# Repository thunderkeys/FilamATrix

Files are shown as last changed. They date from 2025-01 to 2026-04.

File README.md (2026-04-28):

# FilamATrix Mod

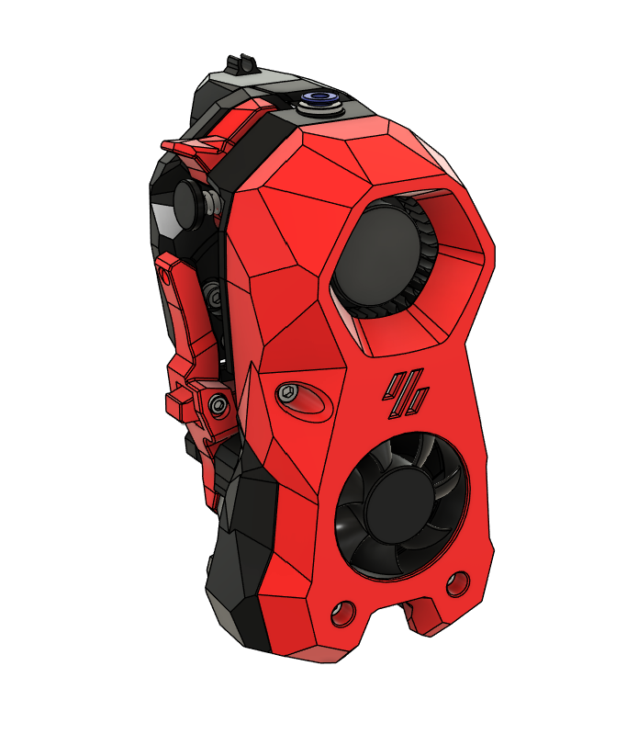
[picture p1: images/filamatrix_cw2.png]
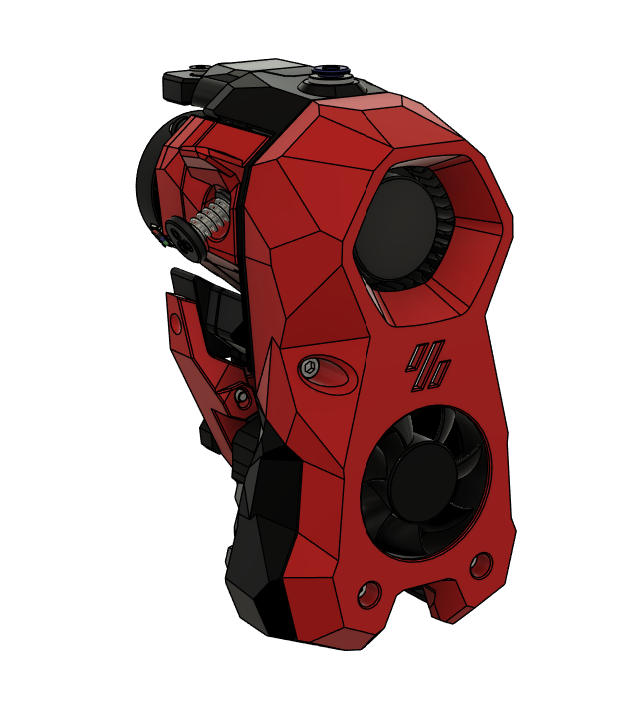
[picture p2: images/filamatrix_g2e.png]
 

FilamATrix is a Stealthburner toolhead filament cutting mod created specifically for the ArmoredTurtle [BoxTurtle](https://github.com/ArmoredTurtle/BoxTurtle) project.  It is an adaptation and cleanup of the [Filametrix](https://github.com/sorted01/Filametrix) and [G2E-Filametrix](https://github.com/IRTrail/G2E-Filametrix) mods. Note the slightly different spelling change - all other documentation within this repository refers to this specific modification.

However, use of BoxTurtle/AFC are not required - this mod can be used anywhere the upstream Filametrix/G2E-Filametrix are.

FilamATrix modifies the [VORON Design](https://www.vorondesign.com) [StealthBurner hotend and Clockwork 2 Extruder](https://github.com/VoronDesign/Voron-Stealthburner/) or [Galileo 2 Extruder](https://github.com/JaredC01/Galileo2/tree/main/galileo2_extruder) to support a kinematic-actuated cutting blade for cleaner, more reliable automated filament changes that also eliminates the need for tip forming.

FilamATrix consolidates the CAD for Filametrix and G2E-Filametrix into a single file and provides a reorganized repository with a clear structure of what files are needed to print.  While both extruders are provided as an option, our recommendation is to use Clockwork 2 - we find users have had the most success with it. The assembly instructions and manual only cover Clockwork 2.

Clockwork 2 supports two toolhead sensors, but some users may only be able to support one due to limited GPIO on the toolhead. With current AFC software, our default recommendation is to not use physical toolhead sensors and instead use the buffer as a [ram sensor](https://www.armoredturtle.xyz/docs/afc-klipper-add-on/installation/buffer-ram-sensor.html).

The print files for FilamATrix have been modified from the original projects with the following changes:

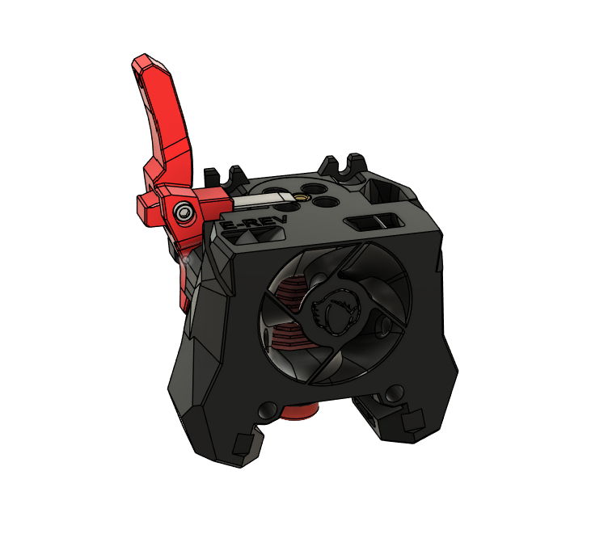
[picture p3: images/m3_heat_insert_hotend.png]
- Hotend mounts/Printheads now use an M3 threaded heat insert (instead of an M3 nut) for simpler installation and maintenance.  Many thanks to [hartk](https://github.com/hartk1213) for this idea!<br>

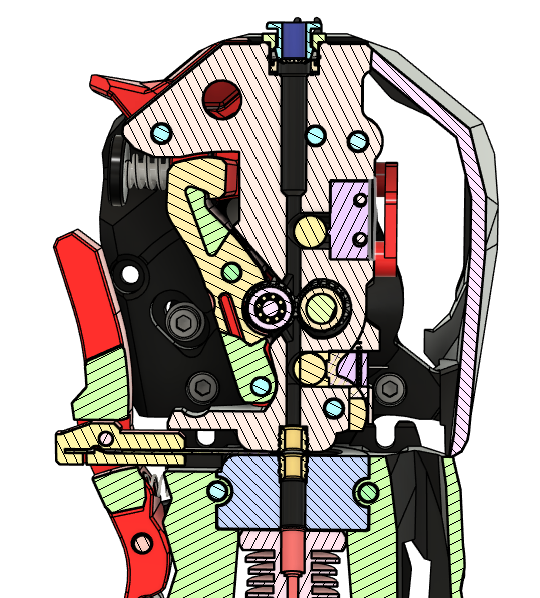
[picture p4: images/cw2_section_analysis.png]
- On Clockwork 2, there is an increased depth for the PTFE tubing to better help guide the filament towards the extruder gears and make insertion less position dependent.<br>

- Cutting arm has been modified to support a full length M2.5x16 FHCS.

- Inclusion of the Beefy Depressor mount as the default.

## Supported hotends
The following hotends are natively supported on this repository:
- Revo Voron
- Dragon HF
- Dragon UHF
- Dragon UHF mini
- Rapido HF v1/v2
- Rapido UHF v1/v2
- Bambulab X1C

The following are user-contributed hotend mounts, please direct any issues with them to their respective creators:
- [TZ V6 2.0 by Adam Storm on Printables](https://www.printables.com/model/1170130-filamatrix-tz-v6-20-hotend-mount)

If you would like to have a hotend mount that you have created added to the above lists, please contact thunderkeys on the [ArmoredTurtle discord](https://discord.gg/armoredturtle) in the toolheads channel.

## Files to print
**LDO Kit users** - If you are running a recent RevD LDO kit with the stock Revo Voron hotend, print [these files](https://github.com/thunderkeys/FilamATrix/blob/main/STLs/LDO/LDO.zip).

**Non-LDO kits/Other users, print these files**
- [beefy_depressor_mount.stl](https://github.com/thunderkeys/FilamATrix/blob/main/STLs/beefy_depressor_mount.stl)
- [beefy_depressor.stl](https://github.com/thunderkeys/FilamATrix/blob/main/STLs/beefy_depressor.stl)
- Respective parts for your extruder - [Clockwork2](https://github.com/thunderkeys/FilamATrix/tree/main/STLs/Clockwork2/README.md) (Recommended) or [Galileo2_Extruder](https://github.com/thunderkeys/FilamATrix/tree/main/STLs/galileo2_extruder/README.md)
- [Stealthburner modified parts](https://github.com/thunderkeys/FilamATrix/tree/main/STLs/Stealthburner/README.md) - pick the set (front+rear) specific to your Printhead/Hotend
- [cutting jig for your hotend](https://github.com/thunderkeys/FilamATrix/blob/main/STLs/README.md) - use a razor blade to cut a section of 2mm ID PTFE to length for your hotend.

**All files**
All files are located on this GitHub in the [STLs folder](https://github.com/thunderkeys/FilamATrix/blob/main/STLs)

## Print settings
All files are to be printed using 'VORON Standard' parts settings/filaments:

| | |
| - | - |
| **3D Printing Process:** Fused Deposition Modeling (FDM) | **Infill Type:** Grid, Gyroid, Honeycomb, Triangle or Cubic |
| **Material:** ABS/ASA | **Infill Percentage:** 40% |
| **Layer Height:** 0.2mm | **Wall Count:** 4 |
| **Extrusion width:** Forced 0.4mm | **Solid Top/Bottom Layers:** 5 |

## Bill of Materials
BoxTurtle kits provided by LDO or Isik's Tech come with all of the physical hardware necessary for FilamATrix, but below is the BOM needed to build it.

 Item    | Quantity | Notes | Source
 ----   | -------- | ------ | -----
ECAS04 Bowden Collet | 1 | | [Amazon](https://www.amazon.com/Pneumatic-Connector-Extruder-Printer-Accessories/dp/B0CFYRGXS3) \| [AliExpress](https://www.aliexpress.us/item/3256805436525602.html)
M3 hex nut | 1 | DIN934 | [McMaster-Carr](https://www.mcmaster.com/90591A250/) \| [AliExpress](https://www.aliexpress.us/item/2255800690659531.html)
M3 washer | 2 | 0.5mm thickness | [KB-3D](https://kb-3d.com/store/inserts-fasteners-adhesives/287-3x6x05mm-shim-ring-washer-pack-of-50-din988-1634423217623.html)
M3x16 BHCS | 1 | | [AliExpress](https://www.aliexpress.us/item/2251832624537980.html)
M3x18 SHCS | 1 | | [AliExpress](https://www.aliexpress.us/item/2251832624557792.html)
M3x20 SHCS | 1 | For Clockwork 2 upper left shroud screw | [AliExpress](https://www.aliexpress.us/item/2251832624557792.html)
M3xD5xL4 Threaded Heatset insert | 5 | | [AliExpress](https://www.aliexpress.us/item/2255800046543591.html)
M3x16 FHCS | 1 | | [AliExpress](https://www.aliexpress.us/item/3256804926092900.html)
M3x18 FHCS | 1 | | [AliExpress](https://www.aliexpress.us/item/3256804926092900.html)
M3x8 SHCS | 1 | | [AliExpress](https://www.aliexpress.us/item/2251832624557792.html)
M3x10, M3x12 or M3x16 SHCS | 2 | 10mm - no backers, 12mm - titanium backers, 16mm - MGN9 rails | [AliExpress](https://www.aliexpress.us/item/3256804926092900.html)
M3 roll-in T-Nut | 2 | | [AliExpress](https://www.aliexpress.us/item/2251832618848960.html)
M2.5x16 SHCS | 1 |  | [AliExpress](https://www.aliexpress.us/item/2251832747871730.html)
0.5mm x 4mm x 25mm coil spring | 1 | A spring from a [common ballpoint pen](https://www.amazon.com/U-S-Government-Pen-Medium-Point/dp/B0055KSO3A) can also work | [Amazon](https://www.amazon.com/uxcell-Compression-Spring-Stainless-Length/dp/B0CGZRR4JT) \| [AliExpress](https://www.aliexpress.us/item/3256803316195677.html)
Type 4 metal hobby blade or OLFA KB4-F/5 8mm chisel blade | 1 | If using the legacy blade holder or G2E), this *may* need to be trimmed to length (approximately 26mm) after purchase. Some suppliers pre-trim the blade (Formbot, West3D Berserker Knifr) | [Amazon Hobby 4](https://www.amazon.com/HARFINGTON-Replacement-Precision-Refills-Scrapbooking/dp/B0CBLRNXSV) \| [OLFA Website](https://olfa.com/products/olfa-kb4-f-5-chisel-art-blades-5pk#shop) \| [Amazon OLFA](https://www.amazon.com/OLFA-9166-KB4-F-Chisel-5-Pack/dp/B000BNXOOU) \| [AliExpress OLFA](https://www.aliexpress.us/item/3256805333623451.html)
D2F limit switch | 1-2 | One per extruder sensor (default with AFC is no physical sensor) | [DigiKey](https://www.digikey.com/en/products/detail/omron-electronics-inc-emc-div/D2F/83270)
5.5mm steel ball-bearing | 1-2 | One per extruder sensor (default with AFC is no physical sensor) | [Amazon](https://www.amazon.com/uxcell-50pcs-Stainless-Bearing-Precision/dp/B09DSH1GL6)
M2x10 Self-tapping screw | 2-4 | Two per extruder sensor | [Amazon](https://www.amazon.com/Hexagon-Socket-Tapping-Screws-M2x10mm/dp/B00YBMROKC)
PTFE Wire | 24-26 gauge | Wire is required to connect the toolhead sensors to your printer. This is extremely build dependent and specifics are not covered here. |
Skittles | User-dependent | Optional, but in case you feel like being a completionist while progressing through the manual. | [Amazon](https://www.amazon.com/Skittles-Original-Candy-Ounce-Jar/dp/B08CS147FX)

## Assembly and Installation
Please review this [interactive manual](https://armoredturtle.xyz/manual.html?manual=filamatrix) for assembly and installation instructions of FilamATrix.

One thing to note is that the stock Stealthburner uses M3x25 SHCS for the upper screws securing the shroud to the extruder. The left screw needs to be an **M3x20** SHCS on FilamATrix to allow the cutting arm to fully depress.

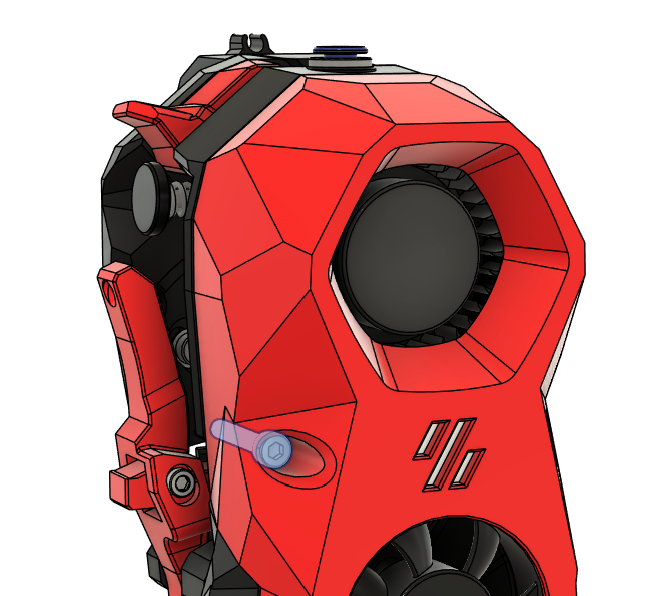
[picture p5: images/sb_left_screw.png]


## Preparing and mounting of the Beefy Depressor

Install M3 heatsets on both sides of the beefy depressor pin. Attach the pin to the mount using the M3x16 FHCS. Thread the M3 hexnut onto the M3x16 BHCS and install that on the end facing into the printer.  Use the hexnut to 'lock' the screw into position, you may wish to use Loctite or VC-3 here on this screw. Careful not to get Loctite on any ABS/ASA printed parts!

Attach the assembled mount to the gantry using M3 screws (place M3 washers between the screws and the printed part).  The length of the screw will likely be printer-dependent, see above BOM for suggested sizes.

Once installed, adjust the height of the pin on the mount and the depth of the screw so it will depress the cutting arm when the toolhead hits against it (going from right to left).

Depending on your printer you may find it more advantageous to mount the beefy depressor at the rear, or at the front.  See below for example mounting locations on an example Voron 2.4 printer gantry.

### Rear
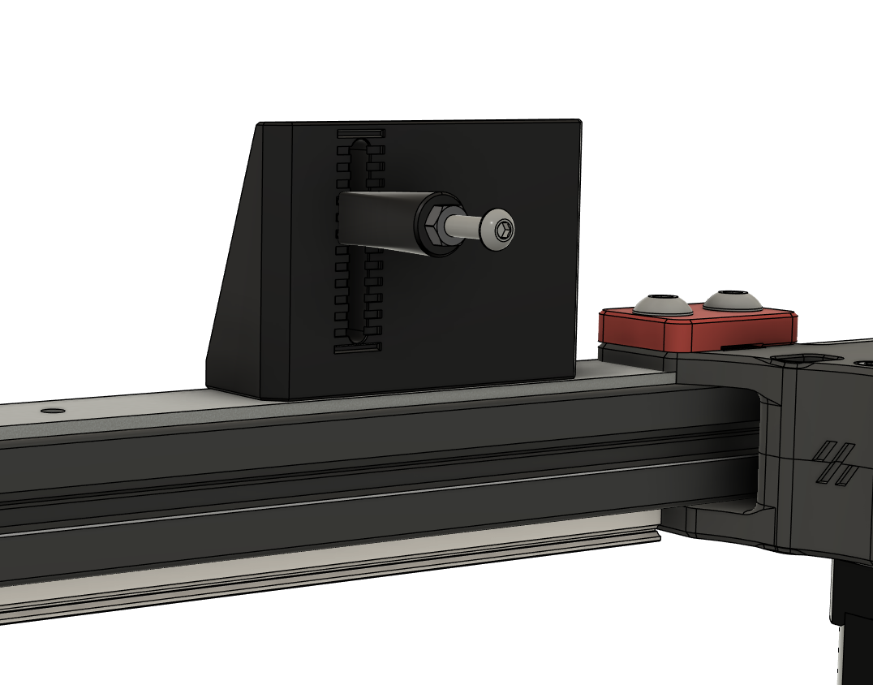
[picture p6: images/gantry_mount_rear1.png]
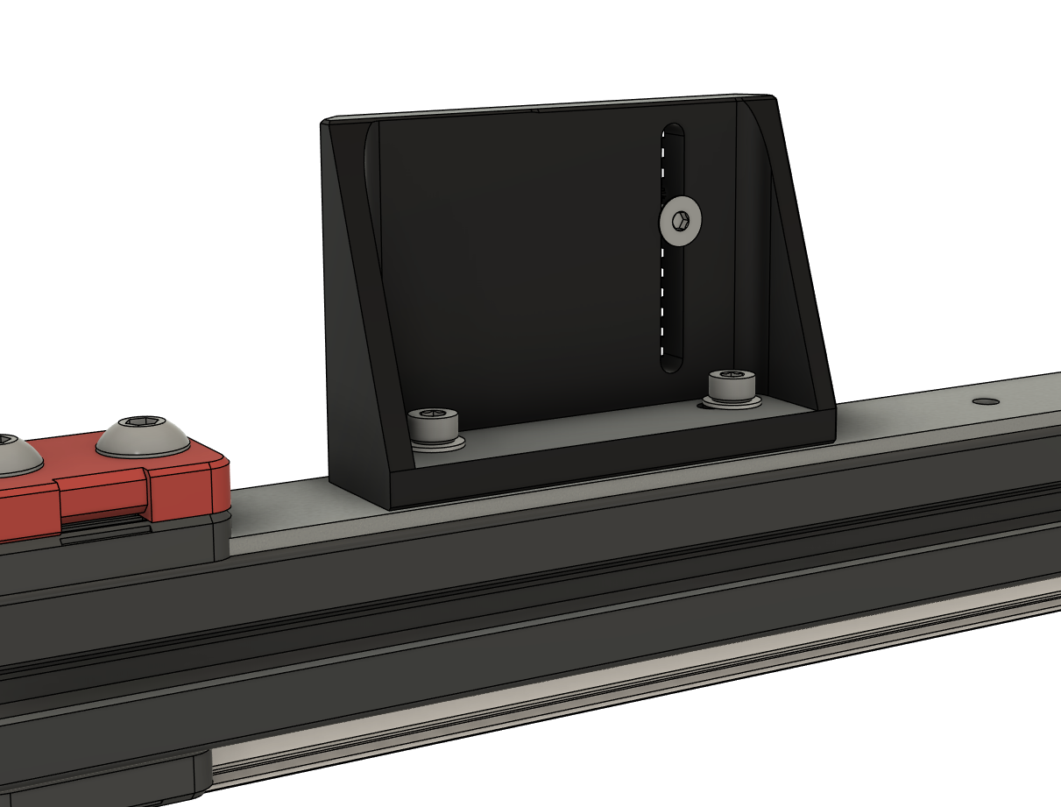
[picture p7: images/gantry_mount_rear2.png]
 

### Front
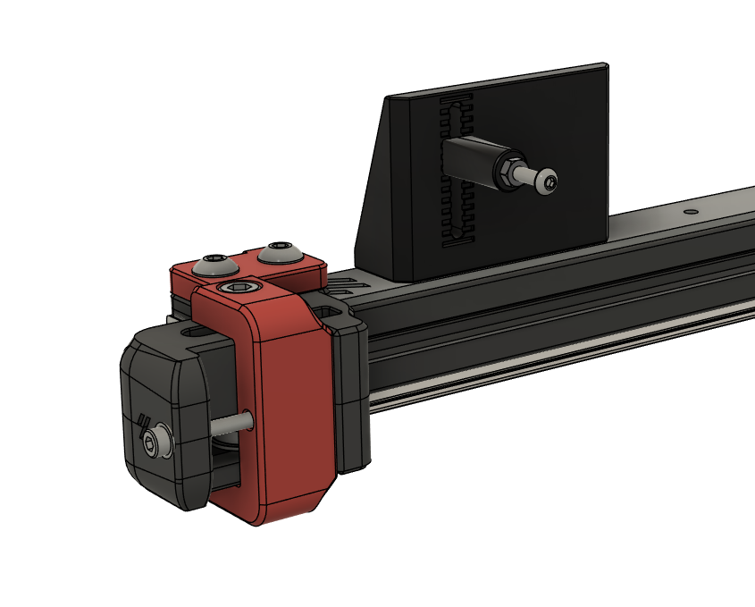
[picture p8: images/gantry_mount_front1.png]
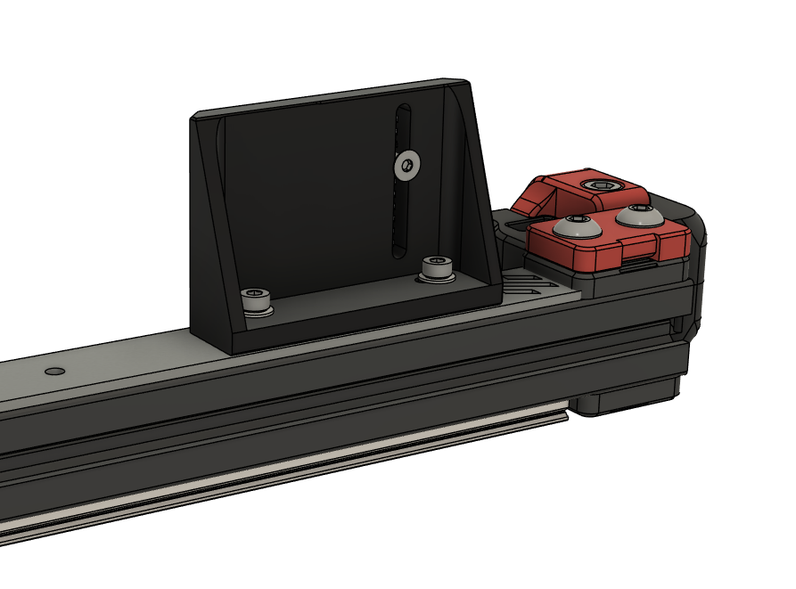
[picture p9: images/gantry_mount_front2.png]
 

## AFC Configuration

Now that FilamATrix is installed, configure your software to leverage it.  If you are using the [AFC Klipper Add-On](https://github.com/ArmoredTurtle/AFC-Klipper-Add-On), you'll need to configure the locations to actuate the cutter arm.
For further guidance you can also see the BoxTurtle [Initial Startup](https://github.com/ArmoredTurtle/BoxTurtle/blob/main/Initial_Startup.md) guide.

If you are using other software, please refer to that project for the correct configuration.

- Home all printer axes (e.g., using G28)
- Use mainsail/fluidd/klipperscreen/etc controls to jog the toolhead near the cutting pin.  This will likely be near X minimum (e.g. X=15-20) and Y maximum if installed in the default location.
- Move the toolhead in 1mm increments until you are just about to depress the pin.  Make note of these coordinates.
- Continue to move the toolhead in 1mm increments until the cutting arm is fully depressed. Make a note of the fully depressed coordinates.
- Ensure ``tool_cut: true`` is set in ``AFC/AFC.cfg`` (it is also recommended to enable the park, kick, poop and wipe macros)
- Update ``AFC/AFC_Macro_Vars.cfg`` with these values as per the comments in the ``_AFC_CUT_TIP_VARS`` section.  

## Acknowledgements
- [Wondro](https://github.com/Wondro) and [ArmoredTurtle](https://github.com/ArmoredTurtle/) for the modified CAD for FilamATrix
- [hartk](https://github.com/hartk1213) for the idea to use an M3 threaded heat insert for the hotend mount
- [sorted01](https://github.com/sorted01) for the original [Filametrix](https://github.com/sorted01/Filametrix) project - you can [donate here](https://www.paypal.com/paypalme/sorted01) if interested
- [IRTrail](https://github.com/IRTrail) for the [G2E-Filametrix](https://github.com/IRTrail/G2E-Filametrix) project (now archived as read-only, as of 2024-12-12).
- [VORON Design](https://www.vorondesign.com) for Stealthburner and Clockwork2
- [JaredC01](https://github.com/JaredC01) for Galileo2
- ChainsDD for the G2E-FilamATrix files to support EBB USB toolhead boards
- [KinematicDigit](https://github.com/kinematicdigit) for the idea on housing full length blades in the knife holder (originally seen with [JabberWocky](https://github.com/kinematicdigit/Jabberwocky)).

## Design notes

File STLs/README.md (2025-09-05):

## Files to print

- [beefy_depressor_mount.stl](https://github.com/thunderkeys/FilamATrix/blob/main/STLs/beefy_depressor_mount.stl) OR [beefy_depressor_mount_cable_chain.stl](https://github.com/thunderkeys/FilamATrix/blob/main/STLs/beefy_depressor_mount_cable_chain.stl) (may be needed if using cable chains on X)
- [beefy_depressor.stl](https://github.com/thunderkeys/FilamATrix/blob/main/STLs/beefy_depressor.stl)
- [razor_safety_cap.stl](https://github.com/thunderkeys/FilamATrix/blob/main/STLs/razor_safety_cap.stl) OR [razor_safety_cap_olfa.stl](https://github.com/thunderkeys/FilamATrix/blob/main/STLs/razor_safety_cap_olfa.stl) - don't cut the bleedy bits of your fingers on the #4 hobby blade
- Respective parts for your extruder - [Clockwork2](https://github.com/thunderkeys/FilamATrix/tree/main/STLs/Clockwork2) or [Galileo2_Extruder](https://github.com/thunderkeys/FilamATrix/tree/main/STLs/galileo2_extruder)
- [Stealthburner modified parts](https://github.com/thunderkeys/FilamATrix/tree/main/STLs/Stealthburner) - pick the set (front+rear) specific to your Printhead/Hotend

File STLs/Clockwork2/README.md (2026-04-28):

# Clockwork2 files

Print one each of:

- [\[a\]\_cutting_arm_clockwork2.stl](https://github.com/thunderkeys/FilamATrix/blob/main/STLs/Clockwork2/%5Ba%5D_cutting_arm_clockwork2.stl)
- [\[a\]\_knife_holder.stl](https://github.com/thunderkeys/FilamATrix/blob/main/STLs/Clockwork2/%5Ba%5D_knife_holder.stl) OR [\[a\]\_knife_holder_olfa.stl](https://github.com/thunderkeys/FilamATrix/blob/main/STLs/Clockwork2/%5Ba%5D_knife_holder_olfa.stl) - don't cut the bleedy bits of your fingers on the sharp blades
- [\[a\]\_latch_ecas.stl](https://github.com/thunderkeys/FilamATrix/blob/main/STLs/Clockwork2/%5Ba%5D_latch_ecas.stl)
- [main_body_clockwork2_no_switch.stl](https://github.com/thunderkeys/FilamATrix/blob/main/STLs/Clockwork2/main_body_clockwork2_no_switch.stl) (default for AFC, no toolhead sensor, uses buffer ramming as sensor) OR [main_body_clockwork2_single_switch.stl](https://github.com/thunderkeys/FilamATrix/blob/main/STLs/Clockwork2/main_body_clockwork2_single_switch.stl) OR [main_body_clockwork2_dual_switch.stl](https://github.com/thunderkeys/FilamATrix/blob/main/STLs/Clockwork2/main_body_clockwork2_dual_switch.stl) 
- [cable_cover_pcb_w_sensor.stl](https://github.com/thunderkeys/FilamATrix/blob/main/STLs/Clockwork2/cable_cover_pcb_w_sensor.stl) OR [cable_cover_pcb.stl](https://github.com/thunderkeys/FilamATrix/blob/main/STLs/Clockwork2/cable_cover_pcb.stl) - the FilamATrix CW2 main body has more room for RP2040 SBB board plugs, and as such requires a newer cable cover mount.

If this is a new build, you will also need to print these upstream Clockwork2 files, which can be obtained from the [VORON Stealthburner repository](https://github.com/VoronDesign/Voron-Stealthburner/) or via links below:

- [\[a\]\_guidler_a.stl](https://github.com/thunderkeys/FilamATrix/blob/main/STLs/Clockwork2/stock/%5Ba%5D_guidler_a.stl)
- [\[a\]\_guidler_b.stl](https://github.com/thunderkeys/FilamATrix/blob/main/STLs/Clockwork2/stock/%5Ba%5D_guidler_b.stl)
- [\[a\]\_latch_shuttle.stl](https://github.com/thunderkeys/FilamATrix/blob/main/STLs/Clockwork2/stock/%5Ba%5D_latch_shuttle.stl)
- [\[a\]\_pcb_spacer.stl](https://github.com/thunderkeys/FilamATrix/blob/main/STLs/Clockwork2/stock/%5Ba%5D_pcb_spacer.stl)
- [motor_plate.stl](https://github.com/thunderkeys/FilamATrix/blob/main/STLs/Clockwork2/stock/motor_plate.stl)
- [chain_anchor_2hole.stl](https://github.com/thunderkeys/FilamATrix/blob/main/STLs/Clockwork2/stock/chain_anchor_2hole.stl) or [chain_anchor_3hole.stl](https://github.com/thunderkeys/FilamATrix/blob/main/STLs/Clockwork2/stock/chain_anchor_3hole.stl) if using cable chains

If you are using an older, pre-release version of Clockwork 2 you will also need to print a new [motor_plate.stl](https://github.com/thunderkeys/FilamATrix/blob/main/STLs/Clockwork2/stock/motor_plate.stl).  In the image below, pre-release is in red, current release is green. See the circled areas for the main change areas to inspect.

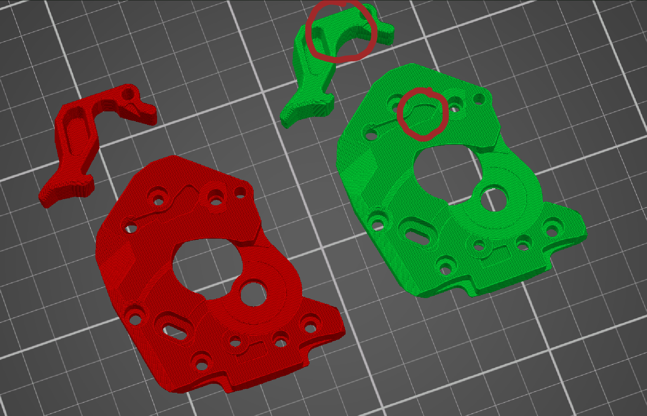
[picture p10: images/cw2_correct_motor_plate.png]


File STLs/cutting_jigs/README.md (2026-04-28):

## PTFE cutting jigs

Print the cutting jig specific to your hotend, which will allow for proper length cuts of your hotend PTFE tube.

- [dragon_hf_ptfe_jig.stl](https://github.com/thunderkeys/FilamATrix/blob/main/STLs/cutting_jigs/dragon_hf_ptfe_jig.stl) (12.8mm)
- [dragon_uhf_ptfe_jig.stl](https://github.com/thunderkeys/FilamATrix/blob/main/STLs/cutting_jigs/dragon_uhf_ptfe_jig.stl) (4.6mm)
- [rapido_ptfe_jig.stl](https://github.com/thunderkeys/FilamATrix/blob/main/STLs/cutting_jigs/rapido_ptfe_jig.stl) (18mm)
- [revo_ptfe_jig.stl](https://github.com/thunderkeys/FilamATrix/blob/main/STLs/cutting_jigs/revo_ptfe_jig.stl) (15.8mm)

## Blade snapping jigs
The following jigs can be used to help snap the OLFA KB4-F/5 or Hobby #4 blades to length, if using G2E or the legacy CW2 parts.  Current CW2 files do not require the blade to be trimmed and can be installed as-is.

The regular versions are sized to 26mm, the shorter versions are 25mm. Install 4 M3 threaded heatset inserts into the bottom and secure the top and bottom sections with 4 M3x10 SHCS screws, sandwiching the blade between the top and bottom halves.  The sharp end of the blade goes into the jig, be careful - sharp things are sharp, avoid the soft squishy bleedy bits.

Once secured, put on eye protection and use a pair of pliers to snap the blade off at the entry point. You can then remove the screws and the blade, install the safety cap and proceed with the installation.

## Hobby #4 blade (what comes in LDO kits)
- [hobby4_top_jig.stl](https://github.com/thunderkeys/FilamATrix/blob/main/STLs/cutting_jigs/hobby4_top_jig.stl)
- [hobby4_bottom_jig_heatsets.stl](https://github.com/thunderkeys/FilamATrix/blob/main/STLs/cutting_jigs/hobby4_bottom_jig_heatsets.stl)
- [hobby4_bottom_jig_heatsets_shorter.stl](https://github.com/thunderkeys/FilamATrix/blob/main/STLs/cutting_jigs/hobby4_bottom_jig_heatsets_shorter.stl)

## OLFA KB4-F/5
- [olfa_top_jig.stl](https://github.com/thunderkeys/FilamATrix/blob/main/STLs/cutting_jigs/olfa_top_jig.stl)
- [olfa_bottom_jig_heatsets.stl](https://github.com/thunderkeys/FilamATrix/blob/main/STLs/cutting_jigs/olfa_bottom_jig_heatsets.stl)
- [olfa_bottom_jig_heatsets_shorter.stl](https://github.com/thunderkeys/FilamATrix/blob/main/STLs/cutting_jigs/olfa_bottom_jig_heatsets_shorter.stl)

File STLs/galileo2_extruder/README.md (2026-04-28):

## Galileo2 Extruder files

Print one each of:

- [\[a\]\_cutting_arm_g2e.stl](https://github.com/thunderkeys/FilamATrix/blob/main/STLs/galileo2_extruder/%5Ba%5D_cutting_arm_g2e.stl)
- [\[a\]\_knife_holder.stl](https://github.com/thunderkeys/FilamATrix/blob/main/STLs/galileo2_extruder/%5Ba%5D_knife_holder.stl) OR [\[a\]\_knife_holder_olfa.stl](https://github.com/thunderkeys/FilamATrix/blob/main/STLs/galileo2_extruder/%5Ba%5D_knife_holder_olfa.stl) - don't cut the bleedy bits of your fingers on the sharp blades
- [front_body_g2e.stl](https://github.com/thunderkeys/FilamATrix/blob/main/STLs/galileo2_extruder/front_body_g2e.stl)
- [rear_body_g2e.stl](https://github.com/thunderkeys/FilamATrix/blob/main/STLs/galileo2_extruder/rear_body_g2e.stl)

If this is a new build, or you are using a non-release version of Galileo 2, you will also need to print these upstream Galileo files, which can be obtained from the [Galileo2 repo](https://github.com/JaredC01/Galileo2/tree/main/galileo2_extruder) or via below:

- [\[a\]\_front_bearing_holder.stl](https://github.com/thunderkeys/FilamATrix/blob/main/STLs/galileo2_extruder/stock/%5Ba%5D_front_bearing_holder.stl)
- [\[a\]\_front_half_g2.stl](https://github.com/thunderkeys/FilamATrix/blob/main/STLs/galileo2_extruder/stock/%5Ba%5D_front_half_g2.stl)
- [\[a\]\_rear_half_g2.stl](https://github.com/thunderkeys/FilamATrix/blob/main/STLs/galileo2_extruder/stock/%5Ba%5D_rear_half_g2.stl)
- [cable_cover.stl](https://github.com/thunderkeys/FilamATrix/blob/main/STLs/galileo2_extruder/stock/cable_cover.stl)
- [idler_bearing_cover.stl](https://github.com/thunderkeys/FilamATrix/blob/main/STLs/galileo2_extruder/stock/idler_bearing_cover.stl)

If using cable chains, ONE of:
- [cable_chain_2_hole.stl](https://github.com/thunderkeys/FilamATrix/blob/main/STLs/galileo2_extruder/stock/cable_chain_2_hole.stl)
- [cable_chain_3_hole.stl](https://github.com/thunderkeys/FilamATrix/blob/main/STLs/galileo2_extruder/stock/cable_chain_3_hole.stl)

If your Galileo2 kit did not come with a metal shim, you can print one:
- [printed_shim.stl](https://github.com/thunderkeys/FilamATrix/blob/main/STLs/galileo2_extruder/stock/printed_shim.stl)

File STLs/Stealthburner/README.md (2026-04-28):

## Stealthburner files

You will need a set (front and rear) 'Printheads' of the modified FilamATrix hotend mounts, that are specific to your hotend.

Current supported hotends are:

- [Revo Voron](https://github.com/thunderkeys/FilamATrix/tree/main/STLs/Stealthburner/Printheads/revo_voron)
- Phaetus Dragon [HF](https://github.com/thunderkeys/FilamATrix/tree/main/STLs/Stealthburner/Printheads/dragon_hf), [UHF](https://github.com/thunderkeys/FilamATrix/tree/main/STLs/Stealthburner/Printheads/dragon_uhf), [UHF mini](https://github.com/thunderkeys/FilamATrix/tree/main/STLs/Stealthburner/Printheads/dragon_uhf_mini)
- Phaetus Rapido [HF](https://github.com/thunderkeys/FilamATrix/tree/main/STLs/Stealthburner/Printheads/rapido_hf), [HF v2](https://github.com/thunderkeys/FilamATrix/tree/main/STLs/Stealthburner/Printheads/rapido_hf_v2), [UHF](https://github.com/thunderkeys/FilamATrix/tree/main/STLs/Stealthburner/Printheads/rapido_uhf), [UHF v2](https://github.com/thunderkeys/FilamATrix/tree/main/STLs/Stealthburner/Printheads/rapido_uhf_v2)

If this is a new build, you will also need the rest of the Stealthburner parts.

- If you have a UHF-style hotend, you will need [this updated Stealthburner shroud](https://github.com/thunderkeys/FilamATrix/blob/main/STLs/Stealthburner/%5Ba%5D_stealthburner_main_body_uhf.stl) if you do not have one already.

All other Stealthburner files should be obtained from the main [VORON Stealthburner repository](https://github.com/VoronDesign/Voron-Stealthburner/), or via the links below:

- [\[a\]\_stealthburner_main_body.stl](https://github.com/thunderkeys/FilamATrix/blob/main/STLs/Stealthburner/stock/%5Ba%5D_stealthburner_main_body.stl) - if using a regular length hotend
- [\[c\]\_stealthburner_LED_diffuser.stl](https://github.com/thunderkeys/FilamATrix/blob/main/STLs/Stealthburner/stock/%5Bc%5D_stealthburner_LED_diffuser.stl)
- [\[o\]\_stealthburner_LED_carrier.stl](https://github.com/thunderkeys/FilamATrix/blob/main/STLs/Stealthburner/stock/%5Bo%5D_stealthburner_LED_carrier.stl)
- [\[o\]\_stealthburner_LED_diffuser_mask.stl](https://github.com/thunderkeys/FilamATrix/blob/main/STLs/Stealthburner/stock/%5Bo%5D_stealthburner_LED_diffuser_mask.stl)

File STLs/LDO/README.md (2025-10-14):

## LDO Stock Kits

If you are already running a stock LDO VORON V2.4r2/Trident Rev D with a Revo Voron hotend, print the below files (or as a [complete zip file](https://github.com/thunderkeys/FilamATrix/blob/main/STLs/LDO/LDO.zip)).

- [beefy_depressor_mount.stl](https://github.com/thunderkeys/FilamATrix/blob/main/STLs/beefy_depressor_mount.stl)
- [beefy_depressor.stl](https://github.com/thunderkeys/FilamATrix/blob/main/STLs/beefy_depressor.stl)
- [razor_safety_cap.stl](https://github.com/thunderkeys/FilamATrix/blob/main/STLs/razor_safety_cap.stl)
- [\[a\]\_cutting_arm_clockwork2.stl](https://github.com/thunderkeys/FilamATrix/blob/main/STLs/Clockwork2/%5Ba%5D_cutting_arm_clockwork2.stl)
- [\[a\]\_knife_holder.stl](https://github.com/thunderkeys/FilamATrix/blob/main/STLs/Clockwork2/%5Ba%5D_knife_holder.stl)
- [\[a\]\_latch_ecas.stl](https://github.com/thunderkeys/FilamATrix/blob/main/STLs/Clockwork2/%5Ba%5D_latch_ecas.stl) (this replaces the upstream \[a\]\_latch.stl Clockwork2 file)
- [cable_cover_pcb_w_sensor.stl](https://github.com/thunderkeys/FilamATrix/blob/main/STLs/Clockwork2/cable_cover_pcb_w_sensor.stl)
- [main_body_clockwork2_single_switch.stl](https://github.com/thunderkeys/FilamATrix/blob/main/STLs/Clockwork2/main_body_clockwork2_single_switch.stl) (this replaces the upstream main_body.stl Clockwork2 file)
- [Revo Voron](https://github.com/thunderkeys/FilamATrix/tree/main/STLs/Stealthburner/Printheads/revo_voron) (these replace the upstream Revo Voron printhead files)
- [revo_ptfe_jig.stl](https://github.com/thunderkeys/FilamATrix/blob/main/STLs/cutting_jigs/revo_ptfe_jig.stl)

Otherwise, you can use these checklists to determine what to print on a new build if you are starting from scratch:
- [Trident RevD](https://thunderkeys.net/voron-stls/orders/ldo-trident-revd.html)
- [V2.4r2](https://thunderkeys.net/voron-stls/orders/ldo-v2-revd.html)

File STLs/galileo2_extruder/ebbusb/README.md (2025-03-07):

Files specific for G2E-FilamATrix using the EBB USB toolhead board, which needs larger clearances.

Credit goes to ChainsDD on ArmoredTurtle discord for these adapted files for FilamATrix.

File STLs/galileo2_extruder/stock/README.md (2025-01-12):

The following files are also needed. They were pulled from the [Galileo2](https://github.com/JaredC01/Galileo2) repository on 2025-01-11.

- [\[a\]\_front_bearing_holder.stl](https://github.com/thunderkeys/FilamATrix/blob/main/STLs/galileo2_extruder/stock/%5Ba%5D_front_bearing_holder.stl)
- [\[a\]\_front_half_g2.stl](https://github.com/thunderkeys/FilamATrix/blob/main/STLs/galileo2_extruder/stock/%5Ba%5D_front_half_g2.stl)
- [\[a\]\_rear_half_g2.stl](https://github.com/thunderkeys/FilamATrix/blob/main/STLs/galileo2_extruder/stock/%5Ba%5D_rear_half_g2.stl)
- [cable_chain_2_hole.stl](https://github.com/thunderkeys/FilamATrix/blob/main/STLs/galileo2_extruder/stock/cable_chain_2_hole.stl) or [cable_chain_3_hole.stl](https://github.com/thunderkeys/FilamATrix/blob/main/STLs/galileo2_extruder/stock/cable_chain_3_hole.stl)
- [cable_cover.stl](https://github.com/thunderkeys/FilamATrix/blob/main/STLs/galileo2_extruder/stock/cable_cover.stl)
- [idler_bearing_cover.stl](https://github.com/thunderkeys/FilamATrix/blob/main/STLs/galileo2_extruder/stock/idler_bearing_cover.stl)
- [printed_shim.stl](https://github.com/thunderkeys/FilamATrix/blob/main/STLs/galileo2_extruder/stock/printed_shim.stl)

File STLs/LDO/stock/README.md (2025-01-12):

The following files are also needed. They were pulled from the [Voron-Stealthburner](https://github.com/VoronDesign/Voron-Stealthburner) repository on 2025-01-11.

- [\[a\]\_stealthburner_main_body.stl](https://github.com/thunderkeys/FilamATrix/blob/main/STLs/Stealthburner/stock/%5Ba%5D_stealthburner_main_body.stl)
- [\[c\]\_stealthburner_LED_diffuser.stl](https://github.com/thunderkeys/FilamATrix/blob/main/STLs/Stealthburner/stock/%5Bc%5D_stealthburner_LED_diffuser.stl)
- [\[o\]\_stealthburner_LED_carrier.stl](https://github.com/thunderkeys/FilamATrix/blob/main/STLs/Stealthburner/stock/%5Bo%5D_stealthburner_LED_carrier.stl)
- [\[o\]\_stealthburner_LED_diffuser_mask.stl](https://github.com/thunderkeys/FilamATrix/blob/main/STLs/Stealthburner/stock/%5Bo%5D_stealthburner_LED_diffuser_mask.stl)

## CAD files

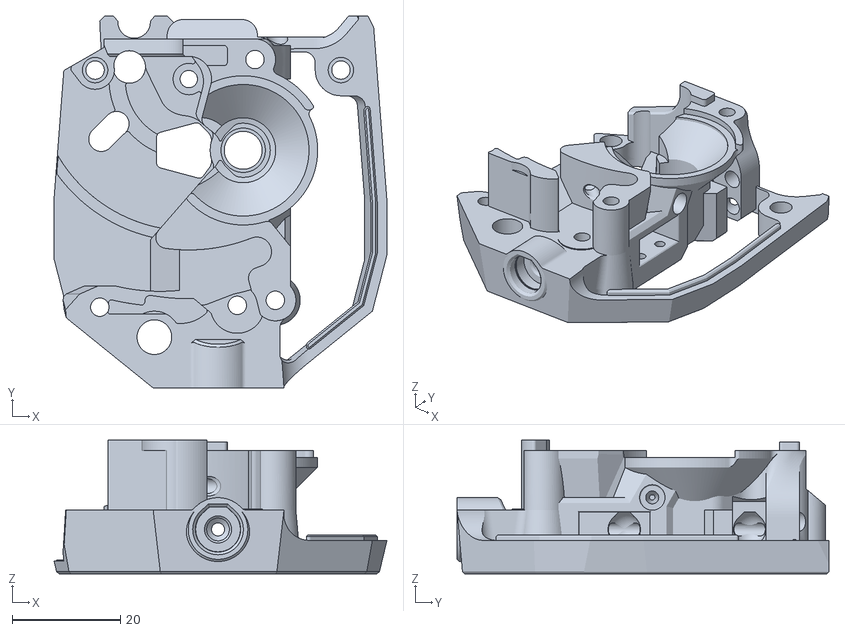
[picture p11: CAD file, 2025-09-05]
STLs/Clockwork2/main_body_clockwork2_dual_switch.stl
61.5 x 68.7 x 24.7

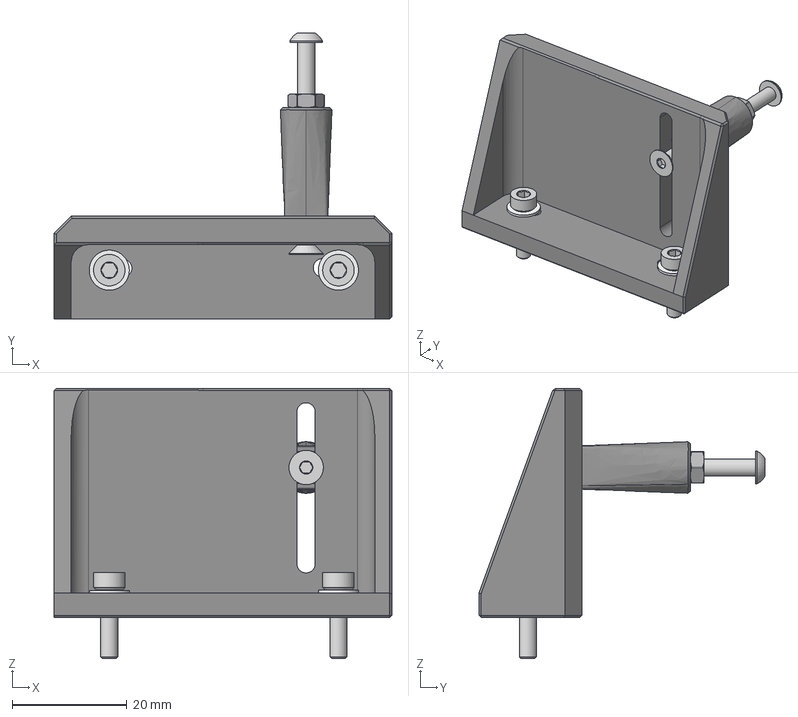
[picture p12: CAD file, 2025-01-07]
CAD/beefy_depressor_mount_assembly.step
59.0 x 50.0 x 47.2 mm
depressor_Part1
depressor_mount_Part1
M3x12 FHCS
M3x16 SHCS x 2
M3 Shim Washer x 2
(Unsaved)
M3_Hexnut
M3x16 BHCS
(Unsaved)_2

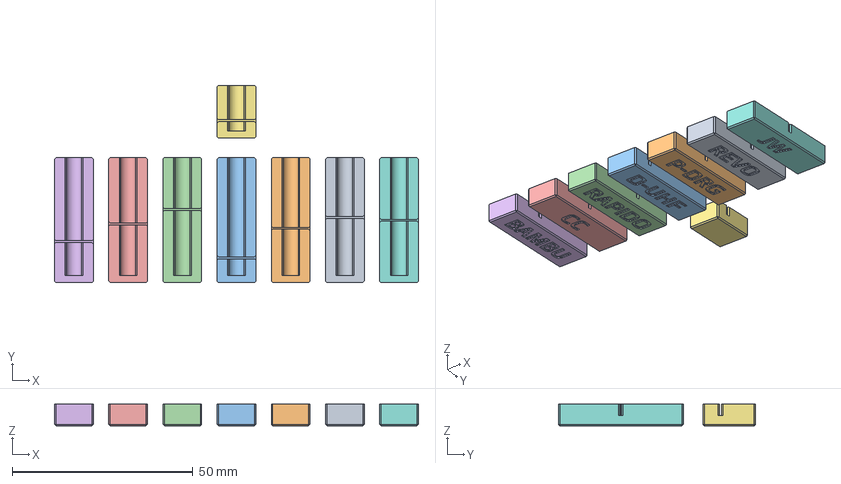
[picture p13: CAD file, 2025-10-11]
CAD/ptfe_cutting_jigs.step
100.7 x 54.6 x 6.00 mm

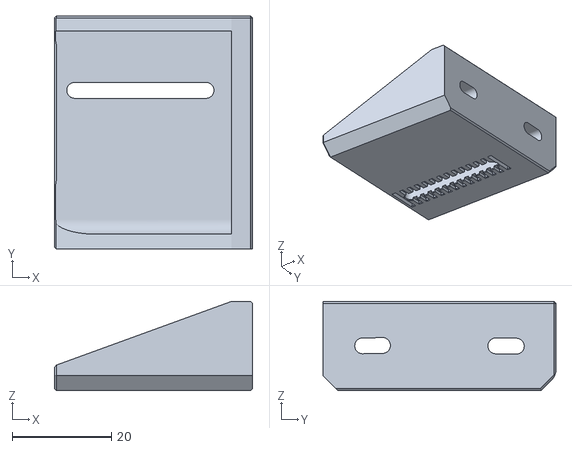
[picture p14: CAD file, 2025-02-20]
STLs/beefy_depressor_mount_cable_chain.stl
40.0 x 47.0 x 18.0

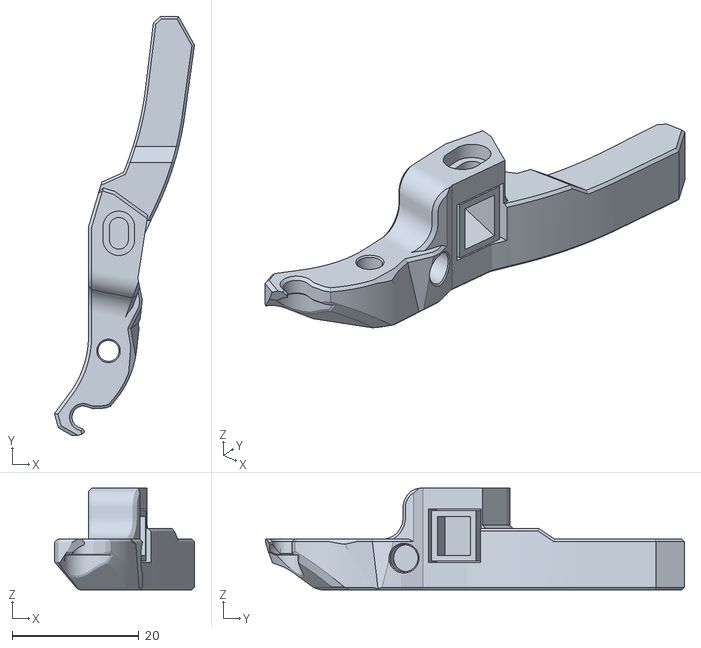
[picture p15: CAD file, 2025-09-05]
STLs/Clockwork2/[a]_cutting_arm_clockwork2.stl
22.1 x 66.1 x 16.0

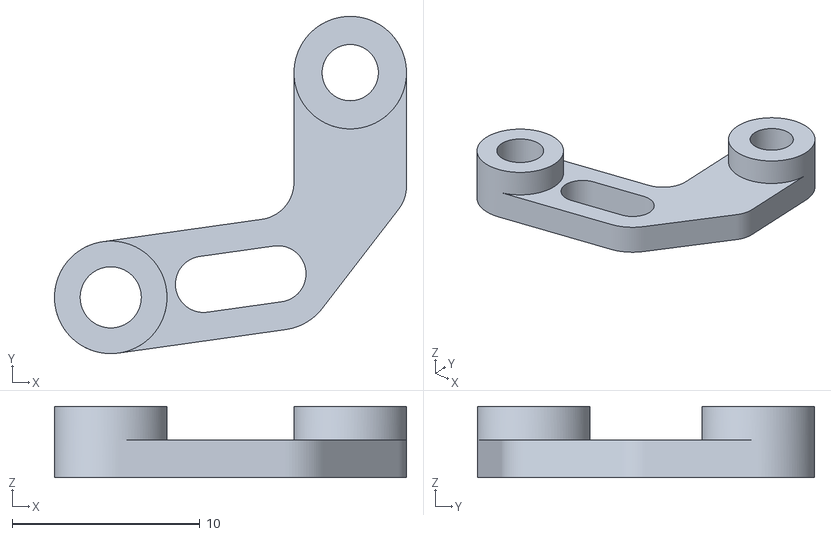
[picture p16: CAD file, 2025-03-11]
STLs/Clockwork2/stock/[a]_pcb_spacer.stl
18.8 x 18.0 x 3.80

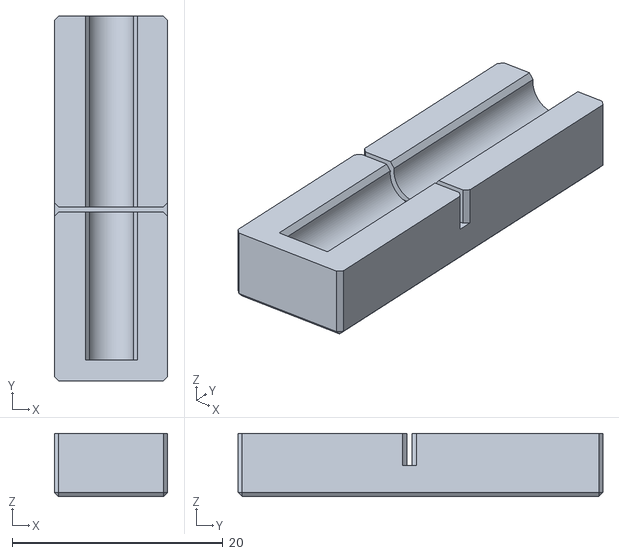
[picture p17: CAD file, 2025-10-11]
STLs/cutting_jigs/chube_compact_ptfe_jig.stl
10.7 x 34.6 x 6.00

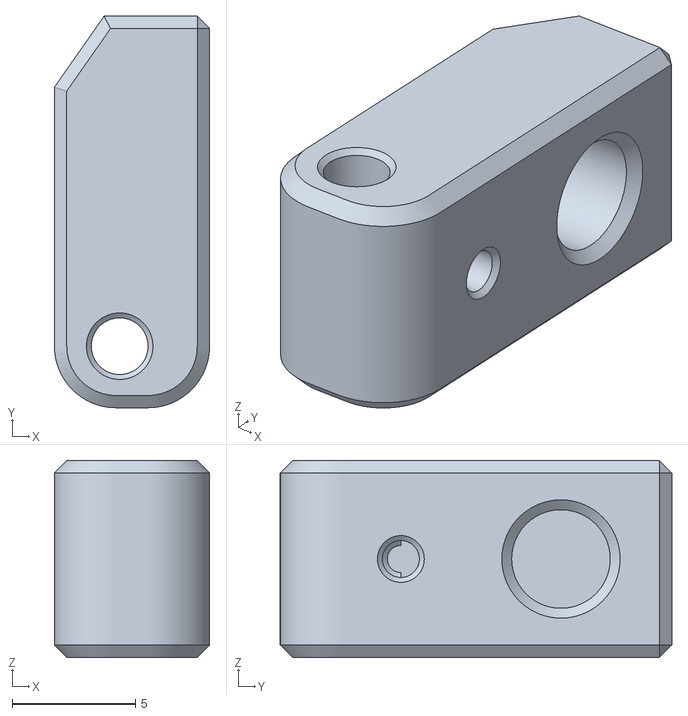
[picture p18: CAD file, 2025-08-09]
STLs/galileo2_extruder/[a]_knife_holder.stl
6.30 x 15.9 x 8.00

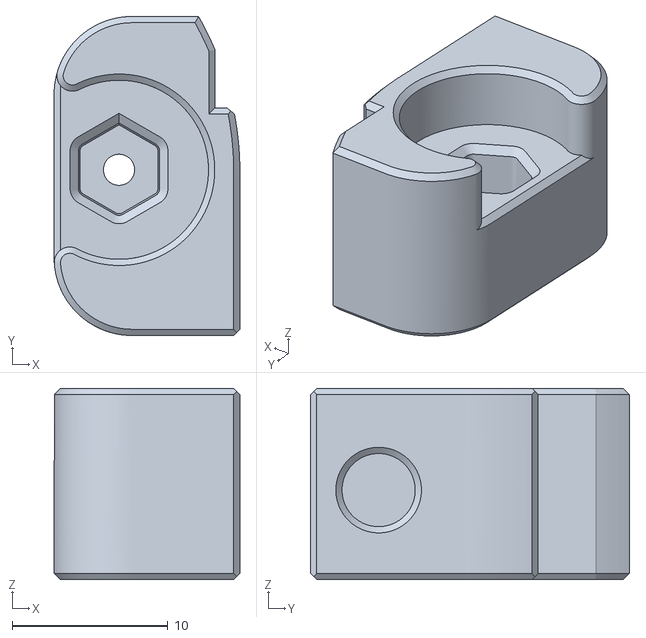
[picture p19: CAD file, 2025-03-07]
STLs/galileo2_extruder/ebbusb/idler_bearing_cover-ebbusb.stl
11.9 x 20.5 x 12.3

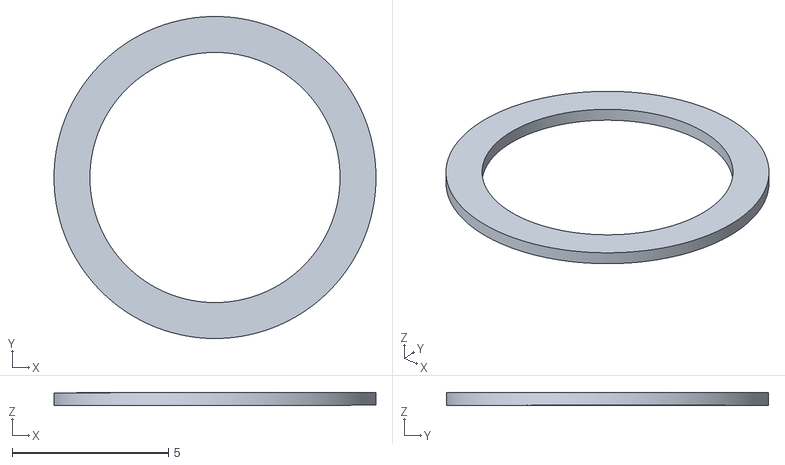
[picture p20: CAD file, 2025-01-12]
STLs/galileo2_extruder/stock/printed_shim.stl
10.3 x 10.3 x 0.4

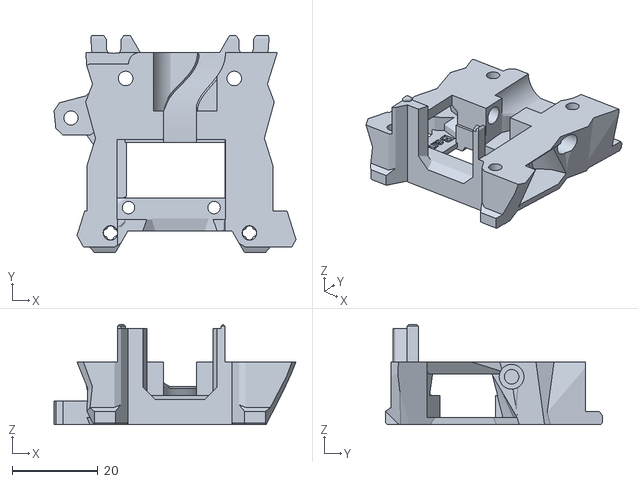
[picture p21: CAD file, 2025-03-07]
STLs/Stealthburner/Printheads/bambu/bambu_rear.stl
56.6 x 50.8 x 23.4

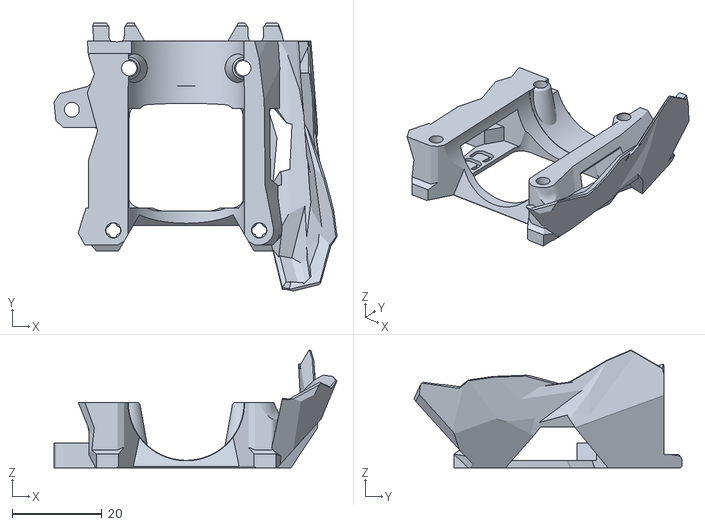
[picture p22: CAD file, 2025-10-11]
STLs/Stealthburner/Printheads/chube_compact/chube_compact_rear.stl
63.0 x 59.7 x 26.3

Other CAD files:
STLs/Stealthburner/[a]_stealthburner_main_body_uhf.stl
STLs/LDO/main_body_clockwork2_single_switch.stl
STLs/Clockwork2/main_body_clockwork2_no_switch.stl
STLs/Clockwork2/main_body_clockwork2_single_switch.stl
CAD/Blade Jig FilamATrix.f3d
CAD/Blade Jig FilamATrix.step
CAD/beefy_depressor_mount_cable_chains.step
STLs/Clockwork2/[a]_knife_holder.stl
STLs/Clockwork2/[a]_knife_holder_olfa.stl
STLs/Clockwork2/cable_cover_pcb.stl
STLs/Clockwork2/stock/[a]_guidler_a.stl
STLs/Clockwork2/stock/[a]_guidler_b.stl
STLs/Clockwork2/stock/[a]_latch_shuttle.stl
STLs/Clockwork2/stock/chain_anchor_2hole.stl
STLs/Clockwork2/stock/chain_anchor_3hole.stl
STLs/Clockwork2/stock/motor_plate.stl
STLs/LDO/[a]_knife_holder.stl
STLs/LDO/[a]_latch_ecas.stl
STLs/LDO/beefy_depressor.stl
STLs/LDO/beefy_depressor_mount.stl
STLs/LDO/cable_cover_pcb_w_sensor.stl
STLs/LDO/razor_safety_cap.stl
STLs/LDO/revo_voron_rear.stl
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

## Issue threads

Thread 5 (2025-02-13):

Beefy Depressor mount issue

ViperWorx, 2025-02-13:
Just a quick heads up that the Beefy Depressor mount does not work with cable chains installed. It is too wide. It needs reducing by 8-12 mm for clearance.  Not an issue for me as I grabbed the STEP and modified it. New STEP file attached for reference.

[Beefy_Depressor_Mount_Cable_Chain.zip](https://github.com/user-attachments/files/18789980/Beefy_Depressor_Mount_Cable_Chain.zip)

thunderkeys, 2025-02-19:
Thanks, will review this!

thunderkeys, 2025-03-17:
this was added in 437d602

Closed 2025-03-17.

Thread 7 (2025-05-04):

Rubbing / Tolerance issues between arm and extrude for G2E with Rapido UHF

valadas, 2025-05-04:
These surfaces are only 0.3mm appart which may not be enough and could rub preventing the blade from retracting after full assembly. I think it that surface could be reduced considerably.

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

valadas, 2025-05-06:
It ends up one of the threaded inserts between the extruder and hotend parts were not inserted far enough and rubbing on the blade. I thill think this tolerance is a bit small but it does work, so feel free to close this issue.

Closed 2025-09-05.

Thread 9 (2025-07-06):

D2F limit switch

the-original-xero-print, 2025-07-06:
I want to buy thé correct limit switch for my stealth Burner toolhead .
In the bom i only Find a link to digikeys Page for switches . But wich one in specific do i need to buy ?
I Cant Find it really in thé discription .
Also are there some connectors for limit switches ? I'm fimmiliar with crimping but not with soldering so it would ben handy tot do it that way . Already thanks :)

thunderkeys, 2025-09-05:
Omron D2F is the stock limit switch specified -- and no not aware of any premade ones, but soldering really not that bad if you give it a shot :)

the-original-xero-print, 2025-09-05:
Hi thanks for thé response .
I did Dolder it the correct way and it worked :)
On this moment i use it as pressence sensor . And i use a own made run out sensor outside of my printer .
But only because it don't works wel when i use it as Runout sensor when my filament run  out on thé toolhead And i extrude it fully thru the extruder it wil not push newly filament in when i reload filament . I don't Know why may be because it's a Little Tangled at the end and it's dificult  tot push thru

Closed 2025-09-21.

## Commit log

2024-12-31 Initial cleanup
    [Bambu Adapter M5 nut.stl, Bambu_Adapter.stl, Cutter body small.obj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]
2024-12-31 Add CAD/STLs
    [SB_Dragon_HF_Rear.stl, SB_Dragon_UHF_Rear.stl, SB_Dragon_UHF_mini_Rear.stl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]
2024-12-31 Not the sworn enemy of Florin
    [[a]_guidler_a.stl, [a]_guidler_b.stl]
2025-01-05 Rename to FilamAtrix mod, new files abound
    [SB_Dragon_HF_Rear.stl, SB_Dragon_UHF_Rear.stl, SB_Dragon_UHF_mini_Rear.stl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]
2025-01-05 Add print list for stock LDO builds
2025-01-05 add stock LDO files for convenience
    [[a]_cutting_arm_clockwork2.stl, [a]_knife_holder_clockwork2.stl, [a]_latch_ecas.stl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]
2025-01-06 Add and document updated cable cover
    [cable_cover_ebb.stl]
2025-01-06 Fix part orientation
    [cable_cover_ebb.stl]
2025-01-06 Make beefy depressor mount work with backers
    [beefy_depressor_mount.stl]
2025-01-06 Update beefy depressor cad
    [beefy_depressor_mount.step, beefy_depressor_mount_assembly.step]
2025-01-06 add razor safety cap
    [razor_safety_cap.stl]
2025-01-06 consolidate knife holders, add olfa options
    [[a]_knife_holder.stl, [a]_knife_holder_g2e.stl, [a]_knife_holder_olfa.stl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]
2025-01-06 Rename cable cover, add option with chamber thermistor mount
    [cable_cover_pcb.stl, cable_cover_pcb_w_sensor.stl]
2025-01-07 Add cutting jigs
    [dragon_hf_ptfe_jig.stl, dragon_uhf_ptfe_jig.stl, ptfe_cutting_jigs.step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]
2025-01-07 Update CAD/README
2025-01-07 Update screw length for backers
2025-01-07 Update beefy depressor step file with hardware
    [beefy_depressor_mount_assembly.step]
2025-01-08 Update washer count in BOM
2025-01-11 Update G2E instructions to include modified rear body to add knife holder clearances
    [rear_body_g2e.stl]
2025-01-12 Include copies of all stock upstream STL files
    [[a]_front_bearing_holder.stl, [a]_front_half_g2.stl, [a]_guidler_a.stl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]
2025-01-14 Reorient for printing
2025-01-14 Fix revo voron mount
2025-01-19 Fix typo in filename
    [rapido_ptfe_jig.stl]
2025-01-21 Update BOM/add note about M3x20 SHCS for SB/CW2 screw difference
2025-02-08 Add razor_safety_cap.stl to LDO.zip and LDO directory
    [razor_safety_cap.stl]
2025-02-11 Correct revo_voron_front to address left duct blockage (sorted/Filametrix issue #68)
2025-02-13 Update LDO.zip to include cable_cover_ebb_w_sensor.stl instead of cable_cover_ebb.stl
    [cable_cover_ebb.stl, cable_cover_pcb_w_sensor.stl]
2025-02-20 Add shorter beefy depressor mount, may be needed if using cable chains
    [beefy_depressor_mount_cable_chain.stl, beefy_depressor_mount_cable_chains.step]
2025-02-21 Add ECAS04 to BOM
2025-02-26 Add blade snapping jigs to repo
    [Blade Jig FilamATrix.f3d, Blade Jig FilamATrix.step, hobby4_bottom_jig_heatsets.stl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]
2025-03-07 Update CAD; include Bambu hotend and G2E support for EBB USB toolhead boards
    [bambu_ptfe_jig.stl, bambu_rear.stl, cable_clamp-ebbusb.stl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]
2025-03-07 Add list of supported hotend mounts
2025-03-11 Add missing [a]_pcb_spacer.stl for clockwork2 stock STLs
    [[a]_pcb_spacer.stl]
2025-08-09 - Update knife holders for larger glue spots; fix links
    [[a]_knife_holder.stl, [a]_knife_holder_clockwork2.stl, [a]_knife_holder_olfa.stl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]
2025-08-16 Add teakettle jig
    [teakettle_ptfe_jig.stl]
2025-09-05 Add support for full length, untrimmed blades on clockwork2 with standard arm.
    [[a]_cutting_arm.stl, [a]_knife_holder.stl, [a]_knife_holder_olfa_full.stl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]
2025-09-05 Update to new CW2 files which use untrimmed, full-length blades. Add new no switch option for CW2.
    [[a]_cutting_arm.stl, [a]_cutting_arm_clockwork2.stl, [a]_cutting_arm_short_clockwork2.stl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]
2025-09-05 More updates for new uncut blades
    [[a]_knife_holder.stl, [a]_knife_holder_olfa.stl]
2025-10-11 Rename Teakettle to Chube Compact
    [chube_compact_ptfe_jig.stl, chube_compact_rear.stl, ptfe_cutting_jigs.step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]
2025-10-14 remove link to knife_holder.stl in main README as that is now extruder-specific
2026-04-28 Fix typos and clarify documentation across READMEs
    Update main README and STL READMEs with grammar fixes, broken link
    fixes, clarifications around AFC default sensor recommendations
    (buffer ram sensor instead of physical toolhead sensors), and notes
    about pre-trimmed blade availability from suppliers.
